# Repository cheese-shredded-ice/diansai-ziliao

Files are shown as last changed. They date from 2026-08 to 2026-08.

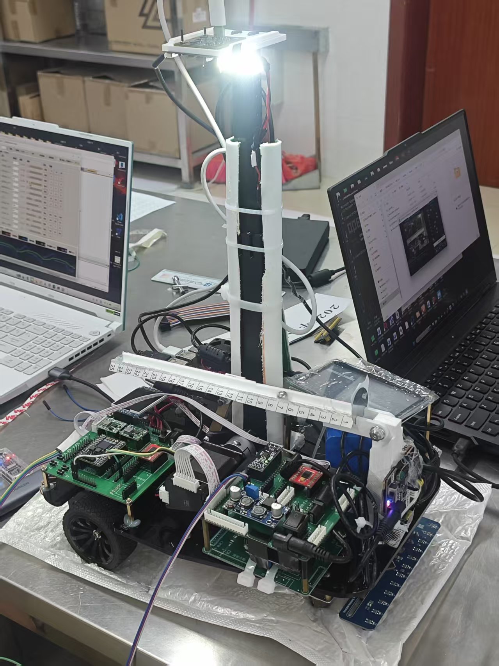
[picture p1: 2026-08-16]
整车图片.jpg

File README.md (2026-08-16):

# 逐飞 MSPM0G3507 电赛工程库

基于逐飞（SeekFree）MSPM0G3507 开发板的电子设计竞赛参赛工程，题目为 **2026 年电赛 H 题：车载平衡滚球运动控制系统**。

## 简介

本仓库包含底车主控程序、外设插件驱动、TI / 逐飞 SDK、PCB 文件、机械结构件，以及钢球视觉识别程序。用于实现小车循线、运动计算与球平衡控制：主控负责循迹与摆杆闭环，RDK X5 负责识别钢球位置并通过串口发送偏移量和速度。

## 目录结构

```
diansai-MBH/
├── 电赛m0/                       # 主控工程与 SDK
│   ├── project/                  # 用户工程
│   │   ├── user/src/main.c       # 主程序（任务调度、循线、显示）
│   │   ├── user/src/isr.c        # 中断服务
│   │   └── keil/hareware/        # 底层硬件驱动（电机/编码器/循迹/陀螺仪等）
│   ├── libraries/                # 逐飞 + TI SDK
│   │   ├── zf_device/            # 外设插件驱动（IMU/OLED/TFT/按键等）
│   │   ├── zf_driver/            # 底层驱动（GPIO/PWM/UART/SPI 等）
│   │   ├── zf_common/            # 通用库
│   │   └── sdk/                  # TI MSPM0 SDK + CMSIS
│   └── ProPrj_*.epro2            # PCB 文件
├── 视觉程序/                      # RDK X5 钢球视觉识别
│   ├── rdk_ball_stable_v5.py     # 主程序：识别钢球并串口发送
│   ├── vision_tuner.py           # 上位机：实时调参与串口联调
│   ├── ball_stable_config.json   # 相机 / ROI / 识别 / 映射 / 串口配置
│   ├── requirements.txt          # Python 依赖
│   └── README.md                 # 视觉端协议与启动说明
└── 结构件/                       # 机械结构件（SolidWorks）
```

## 功能特性

- **循线**：12 路循迹传感器 + PID 循线控制
- **运动计算**：编码器测速 + JY901P 陀螺仪航向 + PID 速度环
- **钢球视觉**：ROI 暗残差识别 + 几何筛选 + 跳变门限，输出位置偏移与速度
- **串口联调**：RDK → 主控 ASCII CSV 协议，调参器可实时开关发送
- **TFT 显示**：TFT180 屏实时显示任务、计时、球位、航向、目标值、速度等
- **任务调度**：按键选择 H 题的 6 个子任务

## 硬件清单

- 主控：逐飞 MSPM0G3507
- 屏幕：TFT180（1.8 寸 TFT）
- 循迹：12 路循迹模块
- 运动：编码器电机 ×2、JY901P 陀螺仪
- 交互：按键 ×4
- 视觉：RDK X5 + USB 摄像头（安装于摆杆凹槽上方，画面覆盖整根摆杆）
- 通信：UART 115200 8N1（RDK TX → 主控 RX，GND 共地）

## 主程序说明

主程序（`project/user/src/main.c`）实现 H 题 6 个任务的调度：

| 任务 | 内容 | 状态 |
|---|---|---|
| 1 | 图传装置验证 | 待实现 |
| 2 | 循线一圈（A→A，≤20s，停车≤2cm） | 已实现 |
| 3 | 静止摆球控制（O→±5cm，误差≤1cm） | 待实现 |
| 4 | A→B 循线 + 球稳定在中心（≤8s） | 待实现 |
| 5 | A→A 一圈 + 球稳定在中心（≤30s） | 待实现 |
| 6 | A→A 一圈 + 球稳定在指定位置（≤30s） | 待实现 |

赛题要求：凹槽内钢球位置检测必须采用摄像头；图传发送模块须固定在车上，回传画面能覆盖整根摆杆。

## 视觉程序说明

视觉端跑在 RDK X5 上，不计算 PID、不输出杆角度。流程：

1. 摄像头采集后立即裁剪 ROI（摆杆凹槽区域）
2. 暗残差二值化 + 形态学 + 圆度/面积筛选，得到钢球横坐标
3. 将 ROI 横坐标线性映射为位置量 `position`（当前量程 0～448，对应摆杆刻度）
4. 计算 `offset = target_position - position`，并对速度做轻量 EMA
5. 按协议发给主控，由主控做摆杆 PID 与电机控制

### 数据定义

```text
position = position_min
         + clamp((x_roi - map_x_left) / (map_x_right - map_x_left), 0, 1)
         × (position_max - position_min)

offset   = target_position - position
```

- 球在目标左侧：`offset > 0`；右侧：`offset < 0`；对准目标：`offset ≈ 0`
- 向右运动：`velocity > 0`；向左：`velocity < 0`
- 只对速度做 EMA，不对位置做滤波，避免一像素抖动被高帧率放大成速度尖峰

### 串口协议

```text
seq,offset_px,speed_px_s,valid\n
```

| 字段 | 含义 | 范围 / 约定 |
|---|---|---|
| `seq` | 帧序号，逐帧 +1，按 `0xFFFFFFFF` 回绕 | 主控按序号去重 |
| `offset_px` | 像素偏移，**右正左负** | ±200 |
| `speed_px_s` | 像素速度，向右为正 | ±20000 |
| `valid` | `1` 本帧可靠跟踪；`0` 丢球或跳变拒绝 | `valid=0` 时两个数值均为 0 |

视觉内部 `offset = target - position` 为右负，发送前取负以匹配主控「右正」约定：

```text
offset_px  = clamp(round(-offset × px_per_unit), -200, 200)
speed_px_s = clamp(round(velocity × px_per_unit), -20000, 20000)
px_per_unit = (map_x_right - map_x_left) / (position_max - position_min)
```

主控必须先看 `valid`，不能把 `valid=0` 的 `offset=0` 当成「球正好在中心」。

### 识别状态

| 状态 | 含义 | 发送 |
|---|---|---|
| `TRACKING` | 当前帧可靠跟踪 | `valid=1`，带真实 offset / velocity |
| `LOST` | 无候选 | `valid=0`，数值清零（短时可用上一速度外推，见 `hold_on_lost_s`） |
| `JUMP_REJECTED` | 候选跳变过大 | 不采用该帧位置，避免用过期数据驱动电机 |

### 启动

在 RDK X5 上：

```bash
cd 视觉程序
DISPLAY=:0.0 python3 -u rdk_ball_stable_v5.py          # 带预览
python3 -u rdk_ball_stable_v5.py --headless            # 无显示
python3 -u vision_tuner.py                             # 调参上位机（串口默认关闭）
```

依赖：`opencv-python`、`numpy`、`pyserial`；调参界面另需 `Pillow`。摄像头占用冲突时先关掉旧进程：

```bash
pkill -f rdk_ball_stable
pkill -f vision_tuner
```

调参器左侧为完整画面（青框为 ROI，紫线为目标位置），右侧可调曝光、二值阈值、ROI、映射和速度滤波。点「串口：关」才会开始向主控发帧。

联调建议：主控先不驱电机，只打印解析结果 → 球放目标左侧确认 offset 为正、右侧为负 → 右移确认 velocity 为正 → 拿走钢球确认 `valid=0` → 再启摆杆 PID。

## 使用说明

1. 使用 Keil MDK 打开 `电赛m0/project/keil/Myzhufei.uvprojx`
2. 编译并下载到 MSPM0G3507 开发板
3. 上电后通过按键选择任务：`KEY_1`/`KEY_2` 切换、`KEY_3` 启动、`KEY_4` 复位
4. 视觉端按上一节启动，确认串口接线与 `ball_stable_config.json` 中的 `serial.port`

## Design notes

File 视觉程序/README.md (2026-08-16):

# 钢球视觉识别

RDK X5 端程序：识别摆杆凹槽内钢球位置，通过串口向主控发送位置偏移和速度。本端不计算 PID，也不输出摆杆角度。

## 文件

| 文件 | 说明 |
|---|---|
| `rdk_ball_stable_v5.py` | 主程序：采集、识别、映射、串口发送 |
| `vision_tuner.py` | 上位机：实时调相机 / ROI / 识别 / 速度参数，可开关串口 |
| `ball_stable_config.json` | 运行配置（相机、ROI、几何、映射、串口） |
| `requirements.txt` | Python 依赖 |

## 依赖

```bash
pip3 install -r requirements.txt
```

中文预览另需字体，例如：

```bash
sudo apt install python3-pil fonts-wqy-zenhei
```

## 启动

先关掉占用摄像头或串口的旧进程：

```bash
pkill -f rdk_ball_stable
pkill -f vision_tuner
```

```bash
DISPLAY=:0.0 python3 -u rdk_ball_stable_v5.py          # 带预览
python3 -u rdk_ball_stable_v5.py --headless            # 无显示
python3 -u vision_tuner.py                             # 调参（串口默认关闭）
```

指定配置：`python3 -u rdk_ball_stable_v5.py --config /path/to.json`

调参器点「串口：关」才会开始发帧。左侧青框为 ROI，紫线为目标位置。

## 数据定义

```text
position = position_min
         + clamp((x_roi - map_x_left) / (map_x_right - map_x_left), 0, 1)
         × (position_max - position_min)

offset   = target_position - position
```

当前量程：`position` 0～448，默认目标 224（摆杆中点附近，以配置为准）。

- 球在目标左侧：`offset > 0`；右侧：`offset < 0`
- 向右运动：`velocity > 0`；向左：`velocity < 0`
- 只对速度做 EMA，不对位置滤波

## 串口协议

接线：RDK TX → 主控 RX，GND 共地。115200 8N1。

```text
seq,offset_px,speed_px_s,valid\n
```

| 字段 | 含义 | 约定 |
|---|---|---|
| `seq` | 帧序号，逐帧 +1，按 `0xFFFFFFFF` 回绕 | 主控按序号去重 |
| `offset_px` | 像素偏移 | **右正左负**，±200 |
| `speed_px_s` | 像素速度 | 向右为正，±20000 |
| `valid` | 本帧是否可靠 | `0` 时两个数值均为 0 |

内部 `offset` 为右负，发送前取负以匹配主控「右正」：

```text
offset_px  = clamp(round(-offset × px_per_unit), -200, 200)
speed_px_s = clamp(round(velocity × px_per_unit), -20000, 20000)
px_per_unit = (map_x_right - map_x_left) / (position_max - position_min)
```

主控必须先看 `valid`，不能把 `valid=0, offset=0` 当成球在中心。

## 识别状态

| 状态 | 含义 | 发送 |
|---|---|---|
| `TRACKING` | 当前帧可靠跟踪 | `valid=1` |
| `LOST` | 无候选 | `valid=0`（`hold_on_lost_s` 内可用上一速度外推） |
| `JUMP_REJECTED` | 候选跳变过大 | 不采用该帧位置 |

检测器可短暂保留上次位置用于下一帧选球，过期位置不会发给主控。

## 配置要点

`ball_stable_config.json` 主要段：

- `camera`：分辨率、曝光、增益等 UVC 参数
- `roi`：摆杆凹槽在画面中的裁剪区域
- `binary`：暗残差阈值与形态学核
- `geometry`：半径 / 面积 / 圆度筛选
- `v5`：边缘放宽、跳变门限随速度放大、丢球保持帧数
- `mapping`：ROI 像素 ↔ 位置量程、目标位置
- `signal`：速度 EMA、死区、最大 dt、丢球外推时间
- `serial`：`port` / `baudrate` / `enabled`

`signal` 建议：

| 项 | 作用 |
|----|---|
| `velocity_alpha` | 速度 EMA 新值权重，建议 0.2～0.4 |
| `velocity_deadband_unit_s` | 低于此值的速度发 0；静止抖动大时可试 1～5 |
| `max_dt_s` | 可靠检测间隔超过此值则速度置 0，避免遮挡恢复后尖峰 |
| `velocity_limit_unit_s` | 原始差分速度限幅 |
| `hold_on_lost_s` | 短时丢球外推时间，`0` 则立即 `valid=0` |

## 快捷键（主程序预览）

| 键 | 作用 |
|----|---|
| `M` | 显示/隐藏二值图 |
| `S` | 保存 ROI、标注图、掩码到 `stable_snapshots/` |
| `R` | 清空跟踪与速度状态 |
| `Q` / `Esc` | 退出 |

## 联调顺序

1. 主控先不驱电机，只打印解析出的 `valid / offset / velocity`
2. 球放目标左侧，确认 `offset > 0`；右侧确认 `offset < 0`
3. 向右移动确认 `velocity > 0`；向左确认 `velocity < 0`
4. 拿走钢球，确认 `valid=0` 且数值为 0
5. 方向与单位无误后再开摆杆 PID：先 P，再速度阻尼，最后按需加 I

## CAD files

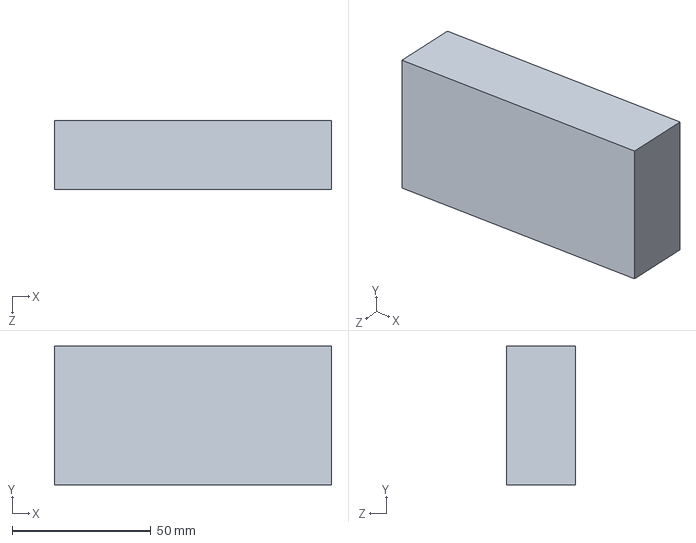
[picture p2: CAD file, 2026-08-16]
结构件/平衡台.SLDASM
100.0 x 50.0 x 25.0 mm

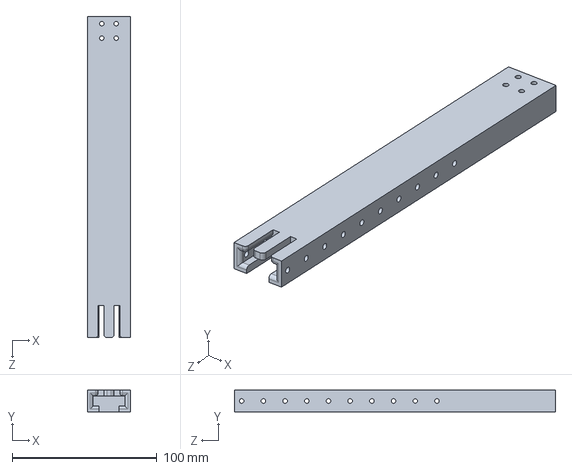
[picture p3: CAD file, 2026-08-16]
结构件/摄像头伸缩1.SLDASM
30.0 x 15.0 x 222.0 mm

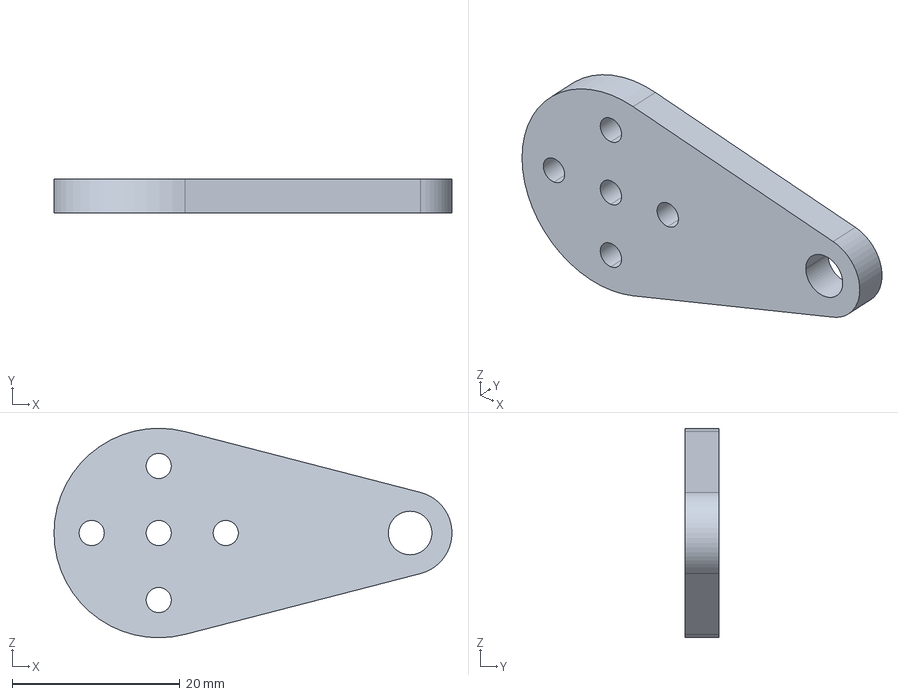
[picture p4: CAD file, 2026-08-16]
结构件/lianjie1.stp
47.5 x 4.00 x 25.0 mm

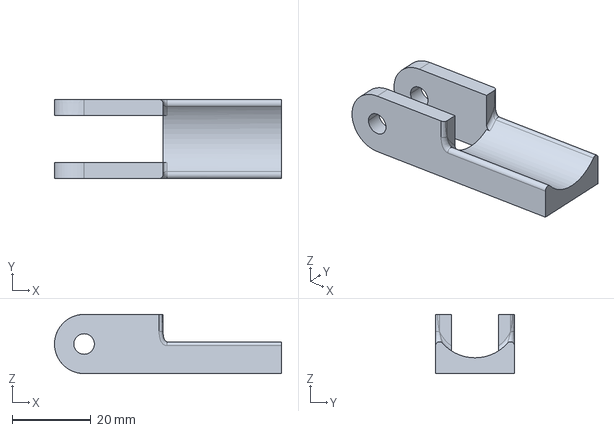
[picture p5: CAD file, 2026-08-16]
结构件/zhijia2.stp
57.5 x 20.0 x 15.0 mm

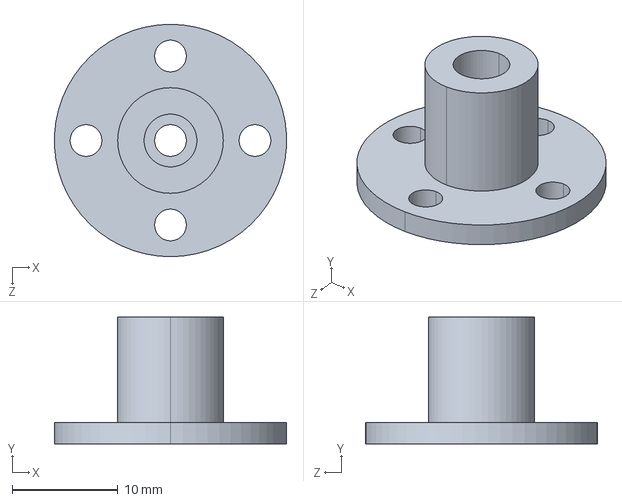
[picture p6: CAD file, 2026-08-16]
结构件/法兰盘.STEP
22.0 x 12.0 x 22.0 mm

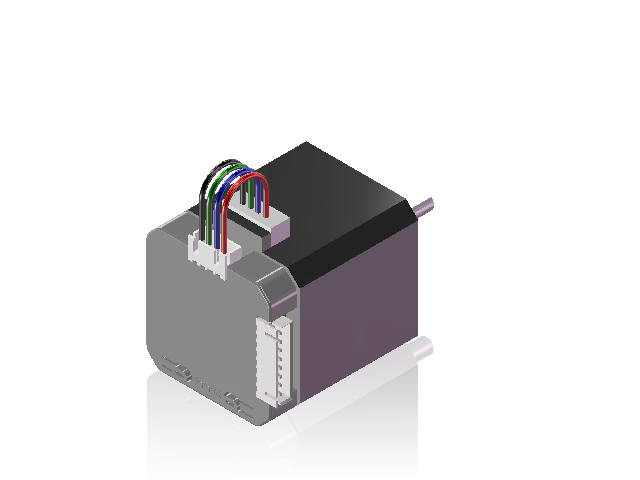
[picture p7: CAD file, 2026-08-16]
结构件/42步进电机40mm带驱动.SLDASM
ts-1145a-b-a_White.step.STEP x 2
User_Library-XH2_54-4P-AW.step.STEP
XH2.54-8P_H-1.step.STEP
Extruded.step.STEP
Extruded-0.step.STEP
42_STEPPER_MOTOR.STEP
SHIM_3x7x3.STEP x 4
M3x6mm_Phillips.STEP x 4
ZDT_X42_V1.2.STEP
WIRE_2.54.STEP

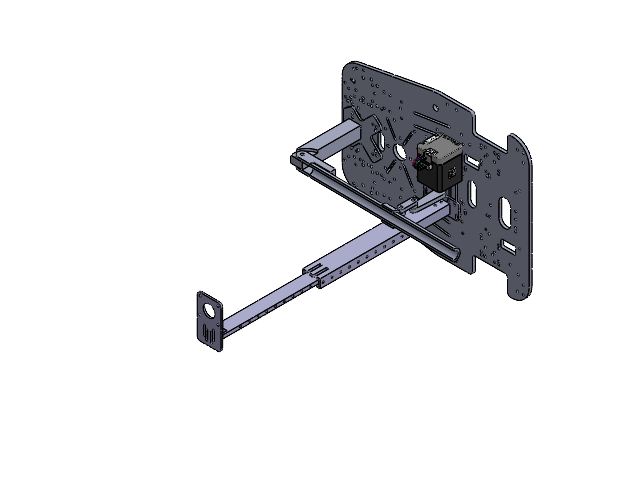
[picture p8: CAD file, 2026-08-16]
结构件/总.SLDASM
R3X增大板（330x230）
水管连杆
连杆2
步进连杆
ts-1145a-b-a_White.step.STEP x 2
User_Library-XH2_54-4P-AW.step.STEP
XH2.54-8P_H-1.step.STEP
Extruded.step.STEP
Extruded-0.step.STEP
42_STEPPER_MOTOR.STEP
SHIM_3x7x3.STEP x 4
M3x6mm_Phillips.STEP x 4
ZDT_X42_V1.2.STEP
WIRE_2.54.STEP
水管

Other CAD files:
结构件/摄像头伸缩2.SLDASM
结构件/摄像头支架顶.SLDASM
结构件/步进连杆.SLDASM
结构件/摄像头支架底座.SLDASM
结构件/总装_R3X四轮两驱底盘(340x240mm).SLDASM
结构件/连杆2.SLDASM
结构件/水管连杆.SLDASM
结构件/总装.SLDASM
结构件/支架2.SLDASM
结构件/5cm.SLDPRT
结构件/Part1.SLDPRT
结构件/CammaMotore.SLDPRT
结构件/CammaPiano.SLDPRT
结构件/Part1.CATPart
结构件/Part10.CATPart
结构件/Part11.CATPart
结构件/Part11.SLDPRT
结构件/Part12.CATPart
结构件/Part17.CATPart
结构件/Part18.CATPart
结构件/Part19.CATPart
结构件/Part2.CATPart
结构件/Part2.SLDPRT
结构件/Part20.CATPart
结构件/Part3.CATPart
结构件/Part3.SLDPRT
结构件/Part4.CATPart
结构件/Part5.CATPart
结构件/Part7.CATPart
结构件/Part8.SLDPRT
结构件/Part9.SLDPRT
结构件/Product1.CATProduct
结构件/Product10.CATProduct
结构件/Product11.CATProduct
结构件/Product2.4.CATProduct
结构件/Product3.CATProduct
结构件/Product5.CATProduct
结构件/R3X四轮差速底盘.SLDASM
结构件/R3X四轮差速底盘.stp
结构件/R3X增大板（330x230）.SLDPRT
结构件/_NPart#93.CATPart
结构件/lianjie2.stp
结构件/main.CATPart
结构件/maxicam.CATProduct
结构件/mian1.CATProduct
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

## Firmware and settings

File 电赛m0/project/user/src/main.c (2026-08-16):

#include "zf_common_headfile.h"
#include "LED.h"
#include "zf_device_oled.h"
#include "ti_msp_dl_config.h" 

// ===== 电赛H题：车载平衡滚球运动控制系统 =====
int8_t TrueFlag=0;           // 当前选中的任务编号 (1~6)
int8_t onFlag=0;             // 任务是否已启动
int8_t task_done[7]={0};     // 各任务完成标志 [1]~[6]，0=未完成 1=已完成
uint32_t task_start_ms=0;    // 任务启动时刻 (ms)
int8_t  t2_line_clear=0;     // 任务2：是否已驶离起跑线
uint8_t t2_mid_cnt=0;        // 任务2：中间传感器连续检测到线的次数
uint32_t task_elapsed_ms=0;  // 任务已用时间 (ms)

int8_t yaw_locked=0;
int8_t yaw_second_locked=0;
static volatile int8_t SenFlag=0;
static volatile int8_t brake_flag = 0;
static volatile uint8_t disp_data[12];   
static volatile float   disp_center=0;     
static volatile uint8_t disp_flag;   

int8_t key_event=0;
int8_t CountBlack=1;
int32_t lastL, lastR;
int32_t SpeedL=0,SpeedR=0;
float Line_er=0;
float initial_yaw=0,steer=0;
float yaw_er=0;
float yaw1_er=0;
float yaw2_er=0;
float steer_yaw;
int32_t steer_kp=9;//陀螺仪
int32_t PID_L,PID_R;
int32_t base_L=900,base_R=900;
int32_t target_L=0,target_R=0;
static float   Line_kp  = 100.0f;    // P：线偏一格，转向量多大
static float   Line_kd  = 5.0f;     // D：线在回正，提前减速
static float   last_center = 0;  
static uint32_t uart_watchdog_ms = 0;        // 距上次收到帧过了多少 ms
static uint32_t last_frames     = 0;         // 上一次的帧计数
static volatile int8_t SenFlag_prev = 0;
static volatile int8_t SenFlag_rise = 0;//白到黑
static volatile int8_t SenFlag_fall =0;//黑道白
static volatile int8_t CountSenFlag_rise=0;//计算
static volatile int8_t CountSenFlag_fall=0;//计算
static volatile int8_t SenFlag_rise_latched = 0;//锁住
static volatile int8_t SenFlag_fall_latched = 0;//锁住
float yaw1=0;
float yaw2=0;
static volatile int8_t  SenFlag_tmp   = 1;       // 中间值
static volatile uint8_t  debounce_cnt = 0;       // 连续同值计数

int8_t Flag =1;              // 选择界面光标 (1~6)

void xunxian(void);
void task2(void);

void pit_key_callback(uint32 event, void *ptr)
{
   // gpio_set_level (B2,0) ;

   
		(void)event;
		(void)ptr;
		
		key_scanner();       // ← 按键扫描放在 PIT 中断里
		JY901P_Controll();
	  if (key_event == 0) {                    // 上一事件没被主循环取走就不覆盖  
        if (key_get_state(KEY_1) == KEY_SHORT_PRESS) { key_event = 1; key_clear_state(KEY_1); }
 	      if (key_get_state(KEY_2) == KEY_SHORT_PRESS) { key_event = 2; key_clear_state(KEY_2); }
	      if (key_get_state(KEY_3) == KEY_SHORT_PRESS) { key_event = 3; key_clear_state(KEY_3); }
	      if (key_get_state(KEY_4) == KEY_SHORT_PRESS) { key_event = 4; key_clear_state(KEY_4); }
		}
		
		
		 uart_watchdog_ms += 10;
		 if (onFlag) { task_elapsed_ms += 10; }  // 任务运行计时
		 if (tracking_ready) {
        tracking_ready = 0;
			  uint8_t white_count = 0;
        for (uint8_t i = 0; i < 12; i++) {
            disp_data[i] = tracking_data[i];
					  if (disp_data[i] == 0) {white_count++;}
						
        }
//				SenFlag=0;
//				SenFlag = 0;
//        for (uint8_t i = 0; i < 12; i++) {
//           if (disp_data[i]) { SenFlag = 1; break; }
//        }
				int8_t sen_raw = (white_count >= 12) ? 0 : 1;
				if (sen_raw == SenFlag_tmp) {
        debounce_cnt++;
          if (debounce_cnt >= 4) {
              SenFlag     = sen_raw;        // 确认切换
              debounce_cnt = 0;
             }
           } else {
        debounce_cnt = 0;
        SenFlag_tmp  = sen_raw;           // 换方向，重新计数
       }	
			}
        /* 存档：当前变成下一帧的"上一帧" */
        SenFlag_prev = SenFlag;
			 
	if (SenFlag_rise) SenFlag_rise_latched = 1;    // 只置 1
      if (SenFlag_fall) SenFlag_fall_latched = 1;
			
			
			
			 if (uart_watchdog_ms >= 200) {     // 超过 500ms 没收到帧
        uart_watchdog_ms = 0;
        tracking_init(115200);         // 软复位 UART2
    }
			
    int32_t nowL = EncoderL_GetCount();
    int32_t nowR = EncoderR_GetCount();
    
    SpeedL = nowL - lastL;   // 这 10ms 内的脉冲增量
    SpeedR = nowR - lastR;
    
    lastL = nowL;
    lastR = nowR;
     //key_scanner();
      //int32_t PID_L,PID_R;
    PID_SET_TARGET_VALVE(&PID_InitMotor_LEFT_Structure,target_L);
	PID_SET_TARGET_VALVE(&PID_InitMotor_RIGHT_Structure,target_R);
    	
    PID_L = PID_SPEED_CIRCLE(&PID_InitMotor_LEFT_Structure,SpeedL);
    PID_R = PID_SPEED_CIRCLE(&PID_InitMotor_RIGHT_Structure,SpeedR);
    
    if (brake_flag==1) {
		PID_L=0;
		PID_R =0;
		PID_InitMotor_LEFT_Structure.Integral   = 0;
		PID_InitMotor_LEFT_Structure.Last_ERROR = 0;
		PID_InitMotor_RIGHT_Structure.Integral   = 0;
		PID_InitMotor_RIGHT_Structure.Last_ERROR = 0; 
	}                
    Motor_SetPWML((int32_t)PID_R);
    Motor_SetPWMR((int32_t)PID_L);
    
}

int main(void)
{
    PID_Init();
	SYSCFG_DL_init();  
	clock_init(SYSTEM_CLOCK_80M);
	uart_gyro_init();
	EncoderR_Init();	
	EncoderL_Init();
    lastL = EncoderL_GetCount();   // ← 在中断开之前存一次初值
    lastR = EncoderR_GetCount(); 
	
	pit_ms_init(PIT_TIM_G0, 10, pit_key_callback, NULL); 
	tft180_init();
	tft180_set_font(TFT180_8X16_FONT  );
	gpio_init(B2, GPO, GPIO_HIGH, GPO_PUSH_PULL);
	gpio_set_level (B2,1) ;
	Motor_Init (); 
	key_init(10);
	tracking_init(115200);               // ← ④ 加在 interrupt_global_enable 之前
   // ===== 界面初始化 =====
	tft180_show_string(0,   0,  "Task:");
	tft180_show_string(0,  17,  "Time:");
	tft180_show_string(108, 17,  "s");
	tft180_show_string(0,  34,  "Ball:");
	tft180_show_string(56, 34,  "Yaw:");
	tft180_show_string(0,  52,  "Tar:");
	tft180_show_string(0,  87,  "Spd:");
	tft180_show_string(0, 103,  "R:");
	tft180_show_string(25,103,  "F:");
	tft180_show_string(50,103,  "S:");
	interrupt_global_enable(0);

    while (1)
    {

        int8_t ev = key_event;
			  key_event = 0;//取走事件
			 if (SenFlag_rise_latched) {SenFlag_rise_latched = 0; CountSenFlag_rise++;}
			 if (SenFlag_fall_latched) {SenFlag_fall_latched = 0; CountSenFlag_fall++;} 
			
			// ===== 行0: 任务选择 + 状态 =====
			tft180_show_int(45, 0, Flag, 1);
			if (onFlag) tft180_show_string(60, 0, "OK ");
			else        tft180_show_string(60, 0, "   ");

			// ===== 行1: 计时 =====
			tft180_show_float(45, 17, (double)task_elapsed_ms / 1000.0, 2, 2);  // 秒.10ms

			// ===== 行2: 球位 + 偏航 =====
			tft180_show_float(30, 34, disp_center, 3, 1);
			tft180_show_float(70, 34, gyro_yaw, 3, 1);

			// ===== 行3: 目标值 =====
			tft180_show_int(30, 52, target_L, 5);
			tft180_show_int(75, 52, target_R, 5);

			// ===== 行4: 12路传感器 =====
			for (uint8_t i = 0; i < 12; i++) {
				tft180_show_int(i * 8, 70, disp_data[i], 1);
			}

			// ===== 行5: 速度 =====
			tft180_show_int(30, 87, SpeedL, 4);
			tft180_show_int(75, 87, SpeedR, 4);


			
				 if (ev) {
			    if (onFlag == 0) { 
                    if      (ev == 1) { Flag++; if (Flag > 6) Flag = 6; } 
			        else if (ev == 2) { Flag--; if (Flag < 1) Flag = 1; }
			        else if (ev == 3) { 
                        TrueFlag = Flag; onFlag = 1; yaw_locked = 0; 
                        task_elapsed_ms = 0;
                        brake_flag = 0;
                        t2_line_clear = 0; t2_mid_cnt = 0;
                        gpio_init(B12, GPO, 1, GPO_PUSH_PULL);
                        CountSenFlag_rise = 0; CountSenFlag_fall = 0; SenFlag_prev = SenFlag;
                    }
			    }
                // KEY_4 任何时候都能复位
                if (ev == 4) { 
                    brake_flag = 1; onFlag = 0; target_L = 0; target_R = 0; 
                    Flag = 1; SenFlag = 0;
                    task_elapsed_ms = 0;
                }
			}

			if (onFlag == 1 && TrueFlag >= 1 && TrueFlag <= 6) {
				gpio_set_level(B2, 0);  // 任务运行指示灯

				// ========== 任务1：图传装置验证 ==========
				if (TrueFlag == 1 && !task_done[1]) {
					// TODO: 图传画面显示 + 录像功能确认
					// 完成条件：图传画面正常，手动按键标记完成
					// task_done[1] = 1; brake_flag = 1;
				}

				// ========== 任务2：循线一圈（A→A），≤20s，停车≤2cm ==========
				else if (TrueFlag == 2 && !task_done[2]) {
					task2();
				}

				// ========== 任务3：静止摆球控制 O→+5cm→-5cm，≤5s，误差≤1cm ==========
				else if (TrueFlag == 3 && !task_done[3]) {
					// TODO: 摆杆控制小球 O→+5cm→折返→-5cm→稳定
					// 完成条件：球停在-5cm附近稳定
					// task_done[3] = 1; brake_flag = 1;
				}

				// ========== 任务4：A→B，球稳定在中心，AB≤8s，误差≤1cm ==========
				else if (TrueFlag == 4 && !task_done[4]) {
					// TODO: 循线从A到B，同时摆杆控制球在O附近
					// 完成条件：到达B点
					// task_done[4] = 1; brake_flag = 1;
				}

				// ========== 任务5：A→A一圈，球稳定在中心，≤30s，误差≤1cm ==========
				else if (TrueFlag == 5 && !task_done[5]) {
					// TODO: 循线一圈，同时摆杆控制球在O附近
					// 完成条件：到达A点停车线，停车
					// task_done[5] = 1; brake_flag = 1;
				}

				// ========== 任务6：A→A一圈，球稳定在任意指定位置，≤30s，误差≤1cm ==========
				else if (TrueFlag == 6 && !task_done[6]) {
					// TODO: 循线一圈，同时摆杆控制球在指定位置
					// 完成条件：到达A点停车线，停车
					// task_done[6] = 1; brake_flag = 1;
				}
			}

       
    }

       
}       

void xunxian(void)
{
	disp_center = tracking_center();
	float d_center = disp_center - last_center;
    last_center    = disp_center;
	Line_er=Line_kp*disp_center+Line_kd * d_center;
	target_L=base_L-Line_er; 
	target_R=base_R+Line_er;
}

void task2(void)
{
	xunxian();  // 循线PID

	// 统计12路传感器检测到黑线的数量
	uint8_t black_cnt = 0;
	for (uint8_t i = 0; i < 12; i++) {
		if (disp_data[i] == 1) black_cnt++;
	}

	// 10秒内不触发停车（避让起跑线等）
	if (task_elapsed_ms < 15000) return;

	// 任意3路黑线 → 刹车
	if (black_cnt >= 3) {
		task_done[2] = 1;
		brake_flag = 1;
		onFlag = 0;          // 暂停计时
	}
}

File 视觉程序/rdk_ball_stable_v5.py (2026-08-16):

#!/usr/bin/env python3
# -*- coding: utf-8 -*-
"""钢球视觉识别与串口发送。

摄像头采集后立即裁剪 ROI，在 ROI 内做暗残差识别、几何筛选和跳变门限，
将横坐标映射为位置量，再向主控发送：
  1. 位置偏移 offset = target_position - position
  2. 位置速度 velocity（仅对速度做 EMA）

本端不计算 PID，也不输出摆杆角度。

串口协议（ASCII CSV，115200 8N1）：
  seq,offset_px,speed_px_s,valid\\n
  offset_px 右正左负（像素），speed_px_s 向右为正（px/s）
  范围：offset ±200，speed ±20000
  valid=0 时两个数值均为 0，由主控执行安全策略

快捷键：
  M      显示/隐藏二值图
  S      保存 ROI、二值图和结果
  R      清空跟踪状态
  Q/ESC  退出
"""

from __future__ import annotations

import argparse
import json
import math
import re
import subprocess
import threading
import time
from collections import deque
from pathlib import Path

import cv2
import numpy as np

try:
    import serial as _pyserial
    _SERIAL_AVAILABLE = True
except ImportError:
    _pyserial = None
    _SERIAL_AVAILABLE = False

try:
    from PIL import Image, ImageDraw, ImageFont
except ImportError:
    Image = None
    ImageDraw = None
    ImageFont = None


SCRIPT_DIR = Path(__file__).resolve().parent
DEFAULT_CONFIG = SCRIPT_DIR / "ball_stable_config.json"
SNAPSHOT_DIR = SCRIPT_DIR / "stable_snapshots"
WINDOW_NAME = "RDK_X5_Ball"
FONT_CANDIDATES = (
    "/usr/share/fonts/opentype/noto/NotoSansCJK-Regular.ttc",
    "/usr/share/fonts/opentype/noto/NotoSansCJKsc-Regular.otf",
    "/usr/share/fonts/truetype/noto/NotoSansCJK-Regular.ttc",
    "/usr/share/fonts/truetype/wqy/wqy-zenhei.ttc",
    "/usr/share/fonts/truetype/arphic/uming.ttc",
    "C:/Windows/Fonts/msyh.ttc",
    "C:/Windows/Fonts/simhei.ttf",
    "C:/Windows/Fonts/simsun.ttc",
)
_FONT_CACHE: dict[int, object | None] = {}
_HEADER_CACHE: np.ndarray | None = None
_HEADER_CACHE_TIME = 0.0
_HEADER_CACHE_STATUS = ""
_HEADER_CACHE_WIDTH = 0


def chinese_font(size: int) -> object | None:
    if size in _FONT_CACHE:
        return _FONT_CACHE[size]
    if ImageFont is None:
        _FONT_CACHE[size] = None
        return None
    for candidate in FONT_CANDIDATES:
        if not Path(candidate).exists():
            continue
        try:
            font = ImageFont.truetype(candidate, size)
            _FONT_CACHE[size] = font
            return font
        except OSError:
            continue
    _FONT_CACHE[size] = None
    return None


def draw_chinese_lines(
    image: np.ndarray,
    lines: list[str],
    positions: list[tuple[int, int]],
    size: int = 18,
    colors: list[tuple[int, int, int]] | None = None,
) -> None:
    """用 Pillow + 中文字体画 UTF-8 文字；不可用时回退为 OpenCV ASCII。"""
    font = chinese_font(size)
    if font is None or Image is None or ImageDraw is None:
        for index, text in enumerate(lines):
            safe = text.encode("ascii", "replace").decode("ascii")
            color = (
                colors[index]
                if colors is not None and index < len(colors)
                else (255, 255, 255)
            )
            cv2.putText(
                image,
                safe,
                (positions[index][0], positions[index][1] + size),
                cv2.FONT_HERSHEY_SIMPLEX,
                0.50,
                color,
                1,
                cv2.LINE_AA,
            )
        return
    rgb = cv2.cvtColor(image, cv2.COLOR_BGR2RGB)
    canvas = Image.fromarray(rgb)
    drawer = ImageDraw.Draw(canvas)
    for index, text in enumerate(lines):
        color_bgr = (
            colors[index]
            if colors is not None and index < len(colors)
            else (255, 255, 255)
        )
        color_rgb = tuple(reversed(color_bgr))
        drawer.text(
            positions[index],
            text,
            font=font,
            fill=color_rgb,
            stroke_width=1,
            stroke_fill=(0, 0, 0),
        )
    image[:] = cv2.cvtColor(np.asarray(canvas), cv2.COLOR_RGB2BGR)


STATUS_ZH = {
    "TRACKING": "跟踪中",
    "LOST": "丢失",
    "JUMP_REJECTED": "跳变拒绝",
}


class SerialComm:
    """串口发送：一行 CSV（seq,offset_px,speed_px_s,valid\\n），只发不收。"""

    def __init__(self, config: dict) -> None:
        self.enabled = bool(config.get("enabled", False))
        self.port = str(config.get("port", "/dev/ttyUSB0"))
        self.baudrate = int(config.get("baudrate", 115200))
        self.ser = None

    def open(self) -> bool:
        if not self.enabled:
            print("[串口] 串口未启用（enabled=false）", flush=True)
            return True
        if not _SERIAL_AVAILABLE:
            print("[串口] pyserial 未安装，串口不可用；请执行：pip3 install pyserial", flush=True)
            return False
        try:
            self.ser = _pyserial.Serial(
                port=self.port,
                baudrate=self.baudrate,
                bytesize=_pyserial.EIGHTBITS,
                stopbits=_pyserial.STOPBITS_ONE,
                parity=_pyserial.PARITY_NONE,
                timeout=0.1,
            )
            print(f"[串口] 已打开 {self.port} @ {self.baudrate}", flush=True)
            return True
        except Exception as exc:
            print(f"[串口] 打开失败: {exc}", flush=True)
            self.ser = None
            return False

    def send(self, frame: bytearray) -> None:
        if self.ser is None or not self.ser.is_open:
            return
        try:
            self.ser.write(frame)
        except Exception as exc:
            print(f"[串口] 发送失败: {exc}", flush=True)

    def close(self) -> None:
        if self.ser is not None and self.ser.is_open:
            self.ser.close()
            print("[串口] 已关闭", flush=True)


def csv_px_per_unit(mapping: dict) -> float:
    """位置单位 → 像素的线性比例：ROI 像素跨度 / 位置量程。"""
    span_px = float(mapping["map_x_right"]) - float(mapping["map_x_left"])
    span_unit = float(mapping["position_max"]) - float(mapping["position_min"])
    return span_px / max(1e-6, span_unit)


def build_csv_line(frame_seq: int, valid: bool, offset: float,
                   velocity: float, px_per_unit: float) -> bytes:
    """构造 ASCII CSV 帧：seq,offset_px,speed_px_s,valid\\n。

    主控约定 offset 右正左负（球在目标右侧为正），速度向右为正，单位像素。
    本端 offset = target - position 为右负，发送前取负；velocity 右正，符号不变。
    """
    if valid:
        offset_px = int(round(-offset * px_per_unit))
        speed_px_s = int(round(velocity * px_per_unit))
        offset_px = max(-200, min(200, offset_px))
        speed_px_s = max(-20000, min(20000, speed_px_s))
        valid_field = 1
    else:
        offset_px = 0
        speed_px_s = 0
        valid_field = 0
    return f"{frame_seq},{offset_px},{speed_px_s},{valid_field}\n".encode("ascii")
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

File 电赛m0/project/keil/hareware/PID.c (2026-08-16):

#include "zf_common_headfile.h"                  // Device header
#include "PID.h"
//void PID_Init(PID_t *P){
//	P->Target=0;
//	P->Actual=0;
//	P->Error0=0;
//	P->Error1=0;
//	P->ErrorInt=0;
//	P->Out=0;
//}	

PID_InitTypeDef PID_InitMotor_LEFT_Structure,PID_InitMotor_RIGHT_Structure;

void PID_Init(void)
{
	PID_InitMotor_LEFT_Structure.Target_Valve=0.0;
	PID_InitMotor_LEFT_Structure.Actual_Valve=0.0;
	PID_InitMotor_LEFT_Structure.ERROR=0.0;
	PID_InitMotor_LEFT_Structure.Last_ERROR=0.0;
	PID_InitMotor_LEFT_Structure.Integral=0.0;
	PID_InitMotor_LEFT_Structure.Kp=10,
	PID_InitMotor_LEFT_Structure.Ki=0;
	PID_InitMotor_LEFT_Structure.Kd=1;
	
	PID_InitMotor_RIGHT_Structure.Target_Valve=0.0;
	PID_InitMotor_RIGHT_Structure.Actual_Valve=0.0;
	PID_InitMotor_RIGHT_Structure.ERROR=0.0;
	PID_InitMotor_RIGHT_Structure.Last_ERROR=0.0;
	PID_InitMotor_RIGHT_Structure.Integral=0.0;
	PID_InitMotor_RIGHT_Structure.Kp=10;
	PID_InitMotor_RIGHT_Structure.Ki=0;
	PID_InitMotor_RIGHT_Structure.Kd=1;
}

void PID_SET_TARGET_VALVE(PID_InitTypeDef *PIDSTRUCTURE,float Target_Temp)
{
	PIDSTRUCTURE->Target_Valve=Target_Temp;
}

float PID_SPEED_CIRCLE(PID_InitTypeDef *Speed,float Actural_Temp)
{
	Speed->ERROR=Speed->Target_Valve-Actural_Temp;
	Speed->Integral+=Speed->ERROR;
	Speed->Actual_Valve=Speed->Kp*Speed->ERROR+Speed->Ki*Speed->Integral+Speed->Kd*(Speed->ERROR-Speed->Last_ERROR);
	Speed->Last_ERROR=Speed->ERROR;
	if(Speed->Actual_Valve >=9000){Speed->Actual_Valve = 9000;}
	if(Speed->Actual_Valve <=-9000){Speed->Actual_Valve = -9000;}
	return Speed->Actual_Valve;
}


//void PID_Update(PID_t *p)
//{
//	p->Error1 = p->Error0;
//	p->Error0 = p->Target - p->Actual;
//	
//	if (p->Ki != 0)
//	{
//		p->ErrorInt += p->Error0;
//	}
//	else
//	{
//		p->ErrorInt = 0;
//	}
//	
//	p->Out = p->Kp * p->Error0
//		   + p->Ki * p->ErrorInt
//		   + p->Kd * (p->Error0 - p->Error1);
//	
//	if (p->Out > p->OutMax) {p->Out = p->OutMax;}
//	if (p->Out < p->OutMin) {p->Out = p->OutMin;}
//  if (p->Out >= p->OutMax && p->Error0 > 0)  p->ErrorInt -= p->Error0;
//	if (p->Out <= p->OutMin && p->Error0 < 0)  p->ErrorInt -= p->Error0;
//}


//#include "zf_common_headfile.h"                  // Device header
//#include "PID.h"
//void PID_Init(PID_t *P){
//	P->Target=0;
//	P->Actual=0;
//	P->Error0=0;
//	P->Error1=0;
//	P->ErrorInt=0;
//	P->Out=0;
//}	
//	
//void PID_Update(PID_t *p)
//{
//	p->Error1 = p->Error0;
//	p->Error0 = p->Target - p->Actual;

//	if (p->Ki != 0)
//	{
//		p->ErrorInt += p->Error0;
//	}
//	else
//	{
//		p->ErrorInt = 0;
//	}

//	p->Out = p->Kp * p->Error0
//	       + p->Ki * p->ErrorInt
//	       + p->Kd * (p->Error0 - p->Error1);

//	if (p->Out > p->OutMax)  p->Out = p->OutMax;
//	if (p->Out < p->OutMin)  p->Out = p->OutMin;

//	// 积分限幅：输出被掐住了就停积分，防止饱和
//	if (p->Out >= p->OutMax && p->Error0 > 0)  p->ErrorInt -= p->Error0;
//	if (p->Out <= p->OutMin && p->Error0 < 0)  p->ErrorInt -= p->Error0;
//}

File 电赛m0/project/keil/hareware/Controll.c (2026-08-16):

#include "zf_common_headfile.h" 
#include "PID.h"
#include "Encoder.h"
#include "Motor.h"
#include "Sensor.h"



#define SPEED_TARGET        800     // 目标速度（每20ms脉冲数）
#define STEERING_TARGET     0.0f    // 目标偏移量（居中）

//static PID_t SpeedPID;         // 速度环 PID  → 控制车整体速度
//static PID_t SteeringPID;      // 转向环 PID  → 控制车转向
//PID_t SpeedPID_L={
//	.Kp=10,
//	.Ki=0.00,
//	.Kd=0,
//	.OutMax=9000,
//  .OutMin=-5000,
//	.Target =400,
//};	
//PID_t SpeedPID={
//	.Kp=10,
//	.Ki=0,
//	.Kd=0,
//	.OutMax=9000,
//  .OutMin=-5000,
//	.Target =1700,
//};	
//PID_t SpeedPID_R={
//	.Kp=10,
//	.Ki=0.00,
//	.Kd=0,
//	.OutMax=9000,
//  .OutMin=-5000,
//	.Target =400,
//};	

//PID_t SteeringPID={
//	.Kp=3,
//	.Ki=0,
//	.Kd=0.0,
//	.OutMax=200,
//  .OutMin=-200,
//	
//};	
// ========== 速度相关变量 ==========
static int32_t speedL = 0;      // 左轮编码器值（每20ms）
static int32_t speedR = 0;      // 右轮编码器值
static float actual_speed = 0;  // 实际速度（左右轮平均）

// ========== 转向相关变量 ==========
static float offset = 0;        // 灰度偏移量

// ========== PWM 输出 ==========
static int32_t pwm_base = 0;    // 速度环输出（基础油门）
static int32_t pwm_steer = 0;   // 转向环输出（差速补偿）
static int32_t pwm_left = 0;    // 左轮最终PWM
static int32_t pwm_right = 0;   // 右轮最终PWM


//void Control_Init(void)
//{
//    
//    PID_Init(&SpeedPID );
//    PID_Init(&SteeringPID);
//}


// 20ms执行一次，在主函数定时中断

//void Control_Update(void)
//{
//    // 读取传感器 
//    // 读编码器（每次读取后自动清零，所以得到的是"每20ms脉冲数"）
//    speedL = EncoderL_GetCount();
//    speedR = EncoderR_GetCount();
//    
//    // 读灰度传感器,计算偏移量
//    read_grayscale();
//    offset = grayscale_calculate();
//    
//    // 速度环 PID 
//    // 实际速度 = 左右轮平均
//    actual_speed = (float)(speedL + speedR) * 0.5f;
//    
//    SpeedPID.Target = (float)SPEED_TARGET;
//    SpeedPID.Actual = actual_speed;
//    PID_Update(&SpeedPID);
//    pwm_base = (int32_t)SpeedPID.Out;      // 基础油门
//    
//    // ========== 3. 转向环 PID ==========
//    SteeringPID.Target = STEERING_TARGET;  // 目标偏移 = 0（居中）
//    SteeringPID.Actual = offset;           // 实际偏移
//    PID_Update(&SteeringPID);
//    pwm_steer = (int32_t)SteeringPID.Out;  // 转向补偿
//    
//    // ========== 4. 合成左右轮 PWM ==========
//    // 差速转向：左加右减 → 右转；左减右加 → 左转
//    pwm_left  = pwm_base + pwm_steer;
//    pwm_right = pwm_base - pwm_steer;
//    
//    //  限幅（0~PWM_DUTY_MAX）为10000
//    if(pwm_left  > PWM_DUTY_MAX) pwm_left  = PWM_DUTY_MAX;
//    if(pwm_left  < -PWM_DUTY_MAX) pwm_left  = -PWM_DUTY_MAX;
//    if(pwm_right > PWM_DUTY_MAX) pwm_right = PWM_DUTY_MAX;
//    if(pwm_right < -PWM_DUTY_MAX) pwm_right = -PWM_DUTY_MAX;
//    
//    // ========== 6. 输出到电机 ==========
//    Motor_SetPWML(pwm_left);
//    Motor_SetPWMR(pwm_right);
//}

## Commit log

2026-08-16 init: 电赛m0 与结构件
    [42步进电机40mm带驱动.SLDASM, 5cm.SLDPRT, CammaMotore.SLDPRT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]
2026-08-16 add: ProPrj 德州仪器 MSPM0G3507 工程文件
2026-08-16 docs: 添加 README、整车图片与循迹运行视频
